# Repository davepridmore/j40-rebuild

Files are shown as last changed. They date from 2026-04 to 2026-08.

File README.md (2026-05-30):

# 1978 Toyota Land Cruiser J40 Rebuild Archive

This repository captures the rebuild of the 1978 Land Cruiser J40 as an evidence-backed archive and project-control workspace:

- WhatsApp chats and media
- manually dropped photos
- tools / parts / labour spend
- legal / admin status tracking
- workstream and phase tracking
- build decisions, milestones, and story outputs

The current setup is intentionally data-first. It gives you a clean place to keep evidence now, while preserving enough structure to produce a restoration story, spend summary, and project control layer as the rebuild moves forward.

## What This Project Tracks

- `tools`: workshop equipment and electrical tools
- `parts`: vehicle parts, consumables, trim, wiring, bodywork materials
- `labour`: painter, electrician, welder, denter, upholstery, mechanical work
- `admin`: registration and other non-restoration vehicle costs, kept separate from restoration totals
- `legal statuses`: ownership transfer, inspection, number-plate position, and document-pack completeness
- `workstreams`: the current phase/state of legal, strip-down, body, electrical, mechanical, interior, and validation work

Only chat content related to this build should be included. The importer treats the `Fj40` group as a build thread and filters the direct `Akbar Khan` export down to restoration-relevant messages only.

## Repository Layout

- `data/config/project.json`: import paths, relevance rules, and project metadata
- `data/config/whatsapp_target_numbers.json`: two-number target map for WhatsApp MCP reads
- `data/manual/expenses.csv`: manually maintained spend ledger with phase/workstream/evidence/payment/delivery/product-link fields
- `data/manual/procurement_queue.csv`: active purchasing queue filtered out of the main expense ledger
- `data/manual/j40_costs_workbook_rows.csv`: normalized extract of `/Users/davidpridmore/Documents/J40_Costs.xlsx` cost-like sheets
- `data/manual/j40_costs_expenses_reconciliation.csv`: workbook-to-ledger match status against `expenses.csv`
- `data/manual/j40_workbook_sheet_profiles.csv`: sheet-by-sheet structure profile across all workbook tabs
- `data/manual/j40_workbook_tidy_backlog.csv`: prioritized workbook tidy issues
- `data/manual/j40_costs_cost_tabs_tidy.csv`: normalized tidy extract of cost tabs (`Tools`, `Parts`, `Substances`, `Wiring`, `Service`)
- `data/manual/reassembly_work_packages.csv`: phased reassembly work packages with gate logic
- `data/manual/reassembly_dependency_edges.csv`: hard and parallel dependencies between reassembly work packages
- `data/manual/component_disposition_plan.csv`: component-level reuse vs refurbish vs repair recommendations
- `data/manual/procurement_decision_matrix.csv`: buy-now vs verify-stock vs defer decisions for open parts rows
- `data/manual/procurement_decision_matrix_pass2.csv`: tub-off-focused second-pass procurement decisions (minimize immediate spend)
- `data/manual/procurement_local_baskets_pass2.csv`: local bundle strategy (rust-minimum, electrical top-up, mechanical Toyota-common bundle)
- `data/manual/brake_system_requirements.csv`: rear brake cable, hard-line, hose, drum, and retaining-clip replacement matrix
- `data/manual/chassis_rubber_requirements.csv`: acquisition/fabrication status matrix for body-mount rubbers, sleeves, cups, shims, and mount hardware
- `data/manual/replacement_pipe_ordering_specs.csv`: curated location/photo/spec matrix for replacement pipes, hoses, hard lines, and the made-to-order coolant pipe sample
- `data/manual/replacement_pipe_photo_intake.csv`: shot-by-shot photo intake checklist for replacement pipe/hose names, placements, media IDs, and measurement targets
- `data/manual/fabrication_handoff_requirements.csv`: UI-facing package list for rubber and electrical fabrication PDF/DXF/SVG handoff
- `data/manual/fabrication/`: ready-to-send DXF/SVG/PDF fabrication packages for rubber recreation and electrical mounting parts
- `data/manual/workbook_tabs/`: per-tab CSV exports for quick review outside Excel
- `data/manual/j40-master-tracker.xlsx`: single Excel workbook generated from `expenses.csv` with `Initial Price`, `Purchase Registration`, `Purchase of Goods`, and `Purchase of Services` tabs
- `data/manual/legal_statuses.csv`: current legal/admin tracker
- `data/manual/workstream_status.csv`: current workstream and phase tracker
- `data/manual/component_jobs.csv`: removable components, outbound jobs, and reassembly-relevant part-flow tracker
- `data/manual/paint_refinish_whatsapp_media_queue.csv`: paint-refinish evidence queue extracted from WhatsApp attachments with send/return/progress buckets
- `data/manual/whatsapp_j40_chat_candidates.csv`: WhatsApp MCP-discovered J40 chat candidates (by profile, score, and fetch status)
- `data/manual/design_decisions.csv`: structured vehicle-design decisions and open design reviews
- `data/manual/photo_inventory.csv`: per-media inventory with component, stage, and confidence tags
- `data/manual/other_build_reference_media.csv`: curated other-build and workshop-sample image manifest for the dashboard
- `data/manual/photo_component_summary.csv`: grouped component summary from the photo inventory
- `data/inbox/photos/`: drop extra project photos here
- `data/raw/imports/`: extracted WhatsApp exports and media
- `data/processed/generated/`: generated message indexes, media indexes, and cost candidates
- `data/pakwheels/<listing_id>/`: listing-gallery snapshots, run history, and archived gallery images
- `data/reference/other_j40_builds/`: drop-zone for images from other J40 builds used as references
- `docs/master-project-plan.md`: the working master plan for the rebuild
- `docs/vehicle-design-spec.md`: the intended end-state of the vehicle itself
- `docs/restoration-story.md`: generated draft story / timeline
- `docs/photo-catalog.md`: generated photo categorization report and lookup guide
- `docs/j40-costs-workbook-reconciliation.md`: workbook registration and reconciliation summary
- `docs/j40-workbook-tabs-and-tidy-plan.md`: workbook-wide tab inventory and tidy plan
- `docs/j40-costs-tidy-extract.md`: normalized cost-tab tidy summary
- `docs/reassembly-dependency-procurement-plan.md`: integrated reassembly sequencing + dependency split + procurement actions
- `docs/procurement-pass2-tub-off.md`: second-pass procurement simplification for tub-off stage and local Pakistan sourcing assumptions
- `docs/suspension-workstream.md`: start-here tracker and installation control sheet for the incoming Ironman Foam Cell suspension set
- `docs/replacement-pipes-workstream.md`: start-here tracker for replacement pipes, hoses, hard lines, and made-to-order pipe samples
- `docs/radiator-workstream.md`: radiator recore/replacement, front retention, hose/cap, and final cooling-system validation workstream
- `docs/ac-hvac-workstream.md`: hidden A/C/HVAC retrofit workstream spanning cabin evaporator, condenser/drier, hose, drain, controls, and wiring
- `docs/gearbox-top-cover-workstream.md`: controlled teardown, inspection, repair/replace, and validation workstream for the gearbox top cover and shift tower
- `docs/gearbox-oil-service-workstream.md`: specific gearbox oil drain, inspection, refill, and buying requirement gate
- `docs/fabrication-handoff-index.md`: send-out index for rubber and electrical fabrication packages
- `photos/index/`: generated lookup folders by component group, specific component, and stage
- `scripts/import_whatsapp.py`: parses chats, extracts media, filters relevance
- `scripts/import_whatsapp_mcp_j40.py`: discovers J40 chats from WhatsApp MCP profiles and exports normalized chat/message/media indexes
- `scripts/generate_story.py`: builds the current restoration story from the indexed evidence
- `scripts/build_master_workbook.py`: builds the single Excel workbook from `expenses.csv`
- `scripts/build_photo_inventory.py`: categorizes `photos/` media and rebuilds inventory + lookup folders
- `scripts/register_cost_workbook.py`: registers and reconciles `J40_Costs.xlsx` against `expenses.csv`
- `scripts/analyze_cost_workbook_tabs.py`: analyzes all workbook tabs, exports per-sheet CSVs, and builds tidy backlog
- `scripts/tidy_cost_workbook.py`: normalizes the five cost tabs into a clean operational extract
- `scripts/build_reassembly_dependency_plan.py`: builds reassembly work packages, dependency graph, component disposition plan, and procurement decision matrix
- `scripts/build_procurement_pass2_tub_off.py`: shrinks the active buy list for tub-off, defers non-baseline scope, and groups local bundle buys
- `scripts/sync_planning_into_cost_workbook.py`: writes all reconciled planning outputs back into `J40_Costs.xlsx` as managed tabs
- `scripts/reconcile_full_cost_workbook.py`: full in-place workbook reconciliation pass (header fixes, mixed-tab splits, tab cleanup, consolidated planning tabs)
- `scripts/build_engine_transmission_comparison.py`: models current-engine vs engine-swap completion costs (including transmission paths) and writes results into `J40_Costs.xlsx`
- `scripts/update_tub_off_refit_and_suspension_plan.py`: writes tub-off to tub-refit control plan, activates the ordered Ironman Foam Cell suspension path, and syncs related workbook tabs
- `scripts/move_wiring_fasteners_to_parts.py`: moves nut/bolt/washer-style rows from `Wiring` into `Parts` so parts tracking stays centralized
- `scripts/track_pakwheels_gallery.py`: snapshots a PakWheels listing gallery and tracks image additions/removals over time
- `scripts/build_project_control_ui.py`: builds `docs/project-control-ui/data.js` for the local project dashboard (workstreams, part ordering, project-step status, WhatsApp samples, and other-build references)
- `scripts/build_paint_refinish_whatsapp_media_queue.py`: extracts paint-refinish photos/videos from WhatsApp media index into send/return/in-progress queues
- `scripts/auth_whatsapp_mcp.sh`: QR-auth helper for WhatsApp MCP profiles (`1` and `2`)
- `tools/generate_rubber_recreation_fabrication_pack.py`: generates the rubber recreation DXF/SVG/PDF fabrication package
- `tools/generate_midi5_plate_mount_rev_c.py`, `tools/generate_midi5_enclosure_rev_d.py`, `tools/generate_relay_mount_rev_c.py`, `tools/generate_relay_mount_rev_d.py`: generate the electrical mounting DXF/SVG/PDF fabrication packages; Rev D is the current MIDI and relay route

## How To Use

1. Drop extra loose photos into `data/inbox/photos/`.
2. Drop reference photos from other J40 builds into `data/reference/other_j40_builds/`.
3. Add curated WhatsApp or workshop sample images to `data/manual/other_build_reference_media.csv`.
4. Update `data/manual/expenses.csv` whenever you buy, quote, receive, install, refund, or defer anything that changes project cost.
   - Put exact online item URLs in `product_link`; multiple URLs can be separated with ` | ` for bundle rows.
5. Set `procurement_stage` in `data/manual/expenses.csv` so each line item stays operationally visible:
   - `purchase_ready`: ready to order now
   - `ordered_pending_delivery`: order has been placed and is waiting to arrive
   - `needs_confirmation`: user says it may already be ordered or delivered, but proof still needs to be reconciled
   - `received_candidate`: likely purchased / delivered, but still needs item-level confirmation
   - `next_phase_purchase`: valid item, but not yet on the critical path
   - `researching`: still being compared or scoped
   - `deferred_until_body_closed`: do not buy until body/floor work reaches the right point
   - `deferred_optional`: non-baseline upgrades or nice-to-haves
   - `received` / `completed`: no longer belongs in the active queue
6. Use `data/manual/procurement_queue.csv` as the working buy list and reconciliation list.
7. Update `data/manual/legal_statuses.csv` whenever a legal/admin step changes state.
8. Update `data/manual/workstream_status.csv` whenever a phase actually moves or gets blocked.
9. Update `data/manual/component_jobs.csv` whenever a removable component is tagged, sent out, returned, stored, or reinstalled.
10. Rebuild the local photo catalog and lookup folders whenever you add files into `photos/`:

```bash
python3 scripts/build_photo_inventory.py
```

To pull selected recent media from Google Photos via Picker API into `photos/`:

```bash
python3 scripts/import_google_photos_picker.py \
  --client-secrets /Users/davidpridmore/.codex/client_secret.json \
  --recent-days 120 \
  --open-browser
```

Personal-account on-demand command (personal OAuth client, import + filter + analysis refresh):

```bash
./scripts/run_personal_photos_picker_on_demand.sh
```

Optional environment overrides:

```bash
CLIENT_SECRETS=/absolute/path/to/oauth_client.json \
RECENT_DAYS=30 \
MOVE_NON_CAR=1 \
./scripts/run_personal_photos_picker_on_demand.sh
```

After import, run:

```bash
python3 scripts/build_photo_inventory.py
python3 scripts/reconcile_component_jobs_photo_inventory.py
python3 scripts/build_paint_refinish_media_queue.py
python3 scripts/build_paint_refinish_whatsapp_media_queue.py
```

`build_paint_refinish_media_queue.py` writes `data/manual/paint_refinish_media_queue.csv` with three evidence buckets:
`prepared_for_send_out`, `returned_from_painter`, and `in_progress_video`.

`build_paint_refinish_whatsapp_media_queue.py` writes `data/manual/paint_refinish_whatsapp_media_queue.csv`
from `data/processed/generated/media_index.csv` and `whatsapp_messages.json` with the same three buckets plus
`classification_confidence` and `classification_reason` for review.

To avoid custom client-secrets entirely, you can use `gcloud` ADC credentials:

```bash
gcloud auth application-default login \
  --scopes=https://www.googleapis.com/auth/photospicker.mediaitems.readonly

python3 scripts/import_google_photos_picker.py \
  --auth-mode adc \
  --recent-days 120
```

Automated ingest mode (recommended in this repo):

- Drop Google Takeout archives into: `data/inbox/takeout/`
- Supported archive formats: `.zip`, `.tgz`, `.tar.gz`
- Cron scanner script: `scripts/scan_takeout_ingest_once.sh`
- Install cron automation: `scripts/install_photo_ingest_cron.sh`
- Remove cron automation: `scripts/uninstall_photo_ingest_cron.sh`
- Current automation status file: `docs/photo_ingest_automation_status.md`

Helper to stage archives from Downloads:

```bash
./scripts/stage_takeout_from_downloads.sh
```

On-demand full ingest + car-related filtering + analysis refresh:

```bash
./scripts/run_photo_ingest_on_demand.sh
```

This command stages archives, ingests media, moves probable non-car files to `photos/non_car_review/`, and refreshes inventory/catalog/reconciliation outputs.

`rclone` note:

- Google Photos Library API policy now limits API reads to media created by the same app/client.
- This means `rclone` is no longer reliable for full phone-library sync in this project.
- Use the Picker on-demand flow above for recent selected media, or Google Takeout ingest for full-library snapshots.

If you still want to run `rclone` (for app-created media only), use:

```bash
./scripts/sync_google_photos_pipeline.sh pridmoredave-gphotos:
```

This command:

- copies recent media from `media/all` into `photos/` (`MAX_AGE` default `540d`)
- rebuilds `data/manual/photo_inventory.csv`
- refreshes `docs/photo-catalog.md`
- refreshes `data/manual/component_jobs_photo_reconciliation.csv` and its report

You can tune the pull window, for example:

```bash
MAX_AGE=180d ./scripts/sync_google_photos_pipeline.sh pridmoredave-gphotos:
```

9. Register and reconcile the external workbook whenever it changes:

```bash
python3 scripts/register_cost_workbook.py --workbook /Users/davidpridmore/Documents/J40_Costs.xlsx
```

10. Run workbook-wide tab analysis and tidy extraction:

```bash
python3 scripts/analyze_cost_workbook_tabs.py --workbook /Users/davidpridmore/Documents/J40_Costs.xlsx
python3 scripts/tidy_cost_workbook.py --workbook /Users/davidpridmore/Documents/J40_Costs.xlsx
```

11. Build reassembly and procurement execution planning artifacts:

```bash
python3 scripts/build_reassembly_dependency_plan.py
```

12. Run the tub-off second-pass procurement simplification:

```bash
python3 scripts/build_procurement_pass2_tub_off.py
```

13. Sync all planning/reconciliation outputs into the main workbook (keeps original tabs and adds managed planning tabs):

```bash
python3 scripts/sync_planning_into_cost_workbook.py --workbook /Users/davidpridmore/Documents/J40_Costs.xlsx
```

The sync command creates a timestamped backup copy before writing:

- `/Users/davidpridmore/Documents/J40_Costs.backup_YYYYMMDD_HHMMSS.xlsx`

14. Run a full workbook reconciliation and simplification pass when tabs drift or mixed content appears:

```bash
python3 scripts/reconcile_full_cost_workbook.py --workbook /Users/davidpridmore/Documents/J40_Costs.xlsx
```

15. Build the engine/transmission scenario comparison and write it into the workbook:

```bash
python3 scripts/build_engine_transmission_comparison.py --workbook /Users/davidpridmore/Documents/J40_Costs.xlsx
```

16. Sync tub-off/refit execution control, mount/rubber procurement, and ordered Ironman Foam Cell suspension decisions:

```bash
python3 scripts/update_tub_off_refit_and_suspension_plan.py --workbook /Users/davidpridmore/Documents/J40_Costs.xlsx
```

17. Move fastener rows from `Wiring` into `Parts`:

```bash
python3 scripts/move_wiring_fasteners_to_parts.py --workbook /Users/davidpridmore/Documents/J40_Costs.xlsx
```

This command creates a backup before edits:

- `/Users/davidpridmore/Documents/J40_Costs.full_reconcile_backup_YYYYMMDD_HHMMSS.xlsx`

18. Rebuild dashboard data for the local project-control UI:

```bash
python3 scripts/build_project_control_ui.py
```

Then start the local dashboard server:

```bash
./start-dashboard.command
```

15. Run:

```bash
python3 scripts/import_whatsapp.py
python3 scripts/import_whatsapp_mcp_j40.py
python3 scripts/build_paint_refinish_whatsapp_media_queue.py
python3 scripts/generate_story.py
python3 scripts/build_master_workbook.py
```

The first command extracts and indexes chats, media, and cost candidates.
The second command discovers J40-related chats from your two WhatsApp MCP profiles and exports normalized chat/message/media tables.
The third command builds the WhatsApp-derived paint evidence queue.
The fourth command produces the draft story and spend snapshot.
The fifth command produces the single Excel workbook for review and sharing, focused on initial pricing and purchase registration control.

The workbook tabs are centered on purchase control:

- `Initial Price`: quoted/initial prices captured so far
- `Purchase Registration`: registration state for each row (`registered`, `registered_needs_confirmation`, `quote_only`, `planned`, `researching`)
- `Purchase of Goods`: goods-only rows (`tools` + `parts`)
- `Purchase of Services`: services-only rows (`labour` + `admin`)

To keep a PakWheels listing gallery tracked over time, run:

```bash
python3 scripts/track_pakwheels_gallery.py --url "https://www.pakwheels.com/used-cars/toyota-land-cruiser-1984-for-sale-in-islamabad-10076971"
```

Each run appends a timestamped snapshot and updates:

- `data/pakwheels/<listing_id>/gallery_runs.csv`
- `data/pakwheels/<listing_id>/gallery_history.csv`
- `data/pakwheels/<listing_id>/archive/` (deduplicated image files)
- `data/pakwheels/<listing_id>/snapshots/<run>/` (per-run URLs + manifest)

## Cost Control Notes

- `phase` and `workstream` tie spend to the plan in `docs/master-project-plan.md`.
- `evidence_ref` should point to a WhatsApp message id, invoice, receipt filename, or similar proof anchor.
- `payment_status` and `delivery_status` should be maintained independently.
- `procurement_stage` is the operational layer on top of financial status; use it to separate "ready to buy now" from "quoted", "received but not fully reconciled", and "deferred".
- Keep `admin` costs separate from restoration costs.
- Quotes and optional upgrades should stay visible, but they should not be confused with confirmed baseline spend.
- `data/manual/procurement_queue.csv` should only contain live items that still need purchase, confirmation, or decision work.

## Seeded Data

The repo already includes:

- the two WhatsApp exports you pointed to in `/Users/davidpridmore/Downloads`
- your current purchase list, separated into received / planned / research items
- known spend items and quote items visible in the chats

Amounts without a confirmed number stay in the ledger with `amount_status=missing` so they are visible but do not distort totals.

## Gmail / Order Status

Project-local MCP is configured in `.ai/mcp/mcp.json` with server `google-orders-receipts` (Gmail + Drive only).

One-time setup:

```bash
bash scripts/auth_orders_receipts_mcp.sh
```

If your OAuth credentials are in a different file, set:

```bash
GOOGLE_WORKSPACE_CREDENTIALS_PATH=/absolute/path/to/credentials.json bash scripts/auth_orders_receipts_mcp.sh
```

Build a full order/receipt verification queue for all `parts` and `tools` rows:

```bash
python3 scripts/build_orders_receipts_audit_queue.py
```

This writes `data/manual/orders_receipts_audit_queue.csv` with:

- audit priority (`high|medium|low`)
- recommended audit status per row
- Gmail/Drive search queries for order confirmation and receipt/invoice proof

Import recent project-relevant Gmail messages:

```bash
python3 scripts/import_google_emails_mcp.py --date-tag 2026-05-18
```

The importer uses the same `j40-orders-receipts` MCP profile, searches recent project/order messages plus exact order references from `data/manual/orders_receipts_audit_queue.csv`, and writes dated `comms_ingest_*` CSV/JSON artifacts under `data/processed/generated/`.

## WhatsApp MCP (2 Numbers)

Project-local MCP is configured in `.ai/mcp/mcp.json` with:

- `whatsapp-number-1`
- `whatsapp-number-2`

Each server uses a separate auth/session directory and media storage path:

- `.ai/mcp/auth/whatsapp-number-1` -> `data/raw/imports/mcp_whatsapp_number_1`
- `.ai/mcp/auth/whatsapp-number-2` -> `data/raw/imports/mcp_whatsapp_number_2`

One-time QR auth for each number profile:

```bash
bash scripts/auth_whatsapp_mcp.sh 1
bash scripts/auth_whatsapp_mcp.sh 2
```

After each login is confirmed, stop the auth process with `Ctrl+C`.

Set your two target numbers in:

- `data/config/whatsapp_target_numbers.json`

Use E.164 format (example: `+923001234567`), one number for each server profile.

Import J40-focused chat metadata and media indexes from the two WhatsApp MCP profiles:

```bash
python3 scripts/import_whatsapp_mcp_j40.py
```

This writes:

- `data/manual/whatsapp_j40_chat_candidates.csv`
- `data/processed/generated/mcp_whatsapp_j40_messages.json`
- `data/processed/generated/mcp_whatsapp_j40_media_index.csv`

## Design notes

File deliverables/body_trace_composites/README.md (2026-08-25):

# J40 Cabin and Floor Concept Release — 2026-08-25

Saved outputs:

- `j40_front_floor_measured_doghouse_trace_20260825_v2.png` — front-floor plan with the high forward enclosure, fast-tapering shoulders, and compact squared seat-side tail.
- `j40_front_doghouse_measured_side_profile_20260825_v1.png` — longitudinal height/profile study.
- `j40_rear_tub_measured_side_bench_layout_20260825_v1.png` — rear-tub side-bench layout preserving the centre aisle.
- `j40_front_cabin_photoreal_transmission_view_20260825_v1.png` — reference-derived appearance study viewed from immediately behind the front-seat line toward the transmission and dashboard.

The labels on the measured sheets are approximate photographic reads and concept geometry. They are not cut-ready drawings. Confirm every dimension square on the stripped body with the drivetrain, shifters, seats, mounts, pedal travel, service access, and drivetrain movement in their final positions.

## Photoreal generation prompt

> Create a reference-derived photorealistic landscape visualization inside the same classic Toyota Land Cruiser J40 cabin. Camera position is just behind the front-seat line, centered and about seated eye height, looking forward toward the transmission tunnel, engine doghouse, pedals, firewall, and the cream dashboard. Show the rebuilt finished interior after the entire floor has been replaced: clean accurately fabricated ribbed steel floor panels and a removable squared sheet-metal transmission/engine cover. The cover must be high and broad at the firewall/dash to clear the real drivetrain shown in the reference photo, then follow its mechanical contour downward and taper aggressively. The part closest to the seats must become extremely narrow, low, and short, terminating before the seat cushions and leaving generous foot/seat clearance on both sides. Use crisp folded facets, small realistic bend radii, a neat perimeter flange with evenly spaced removable fasteners, subtle seams, and two correctly positioned gear/transfer levers through tidy black rubber boots on the high forward portion. Finish the new floor and cover in durable satin warm ivory matching the dashboard, with believable minor texture and soft reflections. Keep authentic J40 dashboard, door openings, inner sill, pedals, proportions, and workshop context from the reference. Include only the lower inner corners of the two front seat cushions at the far left and right foreground so the narrow short rear tail and clearance are obvious. No people, no labels, no dimension text, no cutaway, no exposed gearbox, no loose tools or clutter. Natural workshop daylight, realistic materials, lens perspective, high detail, documentary automotive restoration photography, 16:9 composition.

Generation references:

- the supplied stripped-cabin/drivetrain photograph
- `j40_front_floor_measured_doghouse_trace_20260825_v2.png`
- `j40_front_doghouse_measured_side_profile_20260825_v1.png`
- `reference_front_drivetrain_profile_20260825.png`

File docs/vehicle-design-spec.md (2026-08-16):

# Vehicle Design Spec

## Purpose

This document defines the intended end-state of the J40 as a vehicle, not just as a project. It turns the current chat history and project evidence into a coherent design target that can guide parts, labour, sequencing, and trade-offs.

## Design Position

- Vehicle: 1978 Toyota Land Cruiser J40
- Current controlled basis: ex-military J40 converted to diesel, with the fitted engine positively identified from the owner-supplied block-stamp photograph as Toyota `2H`, serial `117299` (`2H-117299`): 3,980 cc, inline-six, 12-valve OHV, naturally aspirated diesel. Classify the fitted gearbox as Toyota `H55F` five-speed with high confidence: the existing whole-assembly photographs show the Toyota H41/H55F-family case and transfer-adaptor layout, while owner confirmation and the earlier WhatsApp/video record establish five forward gears. A unique gearbox assembly serial has not been captured; visible `33111`, `BYD`, and separate `3` marks are casting/part marks, not a serial. The August 2 steering photographs identify the as-fitted unit by housing, valve-head, port, sector-shaft, pitman-arm and pedestal-mount geometry as a Toyoda Koki late-40-Series factory-type hydraulic steering gear with high confidence. It is not original as-built equipment for this 1978 chassis, but is consistent with a later J40-family retrofit; the raised `25050` is a casting identifier, not a serial or complete Toyota service number. Exact `44110-xxxxx` identity remains unconfirmed.
- Design mode: OE-adjacent restoration with selective usability upgrades
- Intended use: reliable road-going classic 4x4 with improved drivability, lower cabin noise, cleaner wiring, and a more coherent interior
- Design rule: preserve the character of the truck while removing obvious hacks, noise, water ingress, and avoidable drivability pain

Evidence basis:

- `mcp_whatsapp_j40_messages.csv:1780` / `2026-05-17T11:05:54Z`, TLC 40 Series Owners: owner note says "1978 ex military, converted to diesel".
- `mcp_whatsapp_j40_messages.csv:1781` / `2026-05-17T11:06:16Z`, TLC 40 Series Owners: group member says it belonged to Jahanzaib from Lahore.
- `mcp_whatsapp_j40_messages.csv:1797` / `2026-05-17T11:47:47Z`, TLC 40 Series Owners: group member says "Your J40 has 2h engine with 5 speed gear. It was sold by Jahanzeb".
- `mcp_whatsapp_j40_messages.csv:1802` / `2026-05-17T12:10:28Z`, TLC 40 Series Owners: group member says Jahanzeb left the group after selling it.
- Owner-supplied block-stamp photograph received 2026-08-02 shows the `2H` engine code followed by serial `117299`. Record the engine as `2H-117299`. The supplied description places it in early-to-mid-1980s production, but no factory serial-to-date record is held in the project, so the build year remains an estimate rather than a procurement datum.

## Design North Star

- Exterior and body should read as a proper J40, not a heavily modernized custom build.
- Mechanical and electrical systems should feel tighter, safer, and more dependable than the current truck.
- Interior should become cleaner, quieter, and more usable without losing the basic utilitarian identity of the vehicle.
- Upgrades should mostly be hidden, reversible, or visually restrained unless there is a clear reason not to do so.

## Design Principles

- `OE-adjacent, not concours`: aim for something that could plausibly have been built well, rather than a museum-original truck.
- `Function over gimmicks`: every visible change should improve use, durability, serviceability, or weather protection.
- `Repair before upgrade`: structural, weather, wiring, and baseline mechanical integrity come before comfort and audio.
- `Document every deviation`: if the build leaves stock, the reason and resulting spec should be recorded.
- `Serviceable by the next person`: wiring, parts choices, and fastener decisions should not trap the next owner or mechanic.

## Evidence-Based Direction

The following signals appear directly in chat evidence and form the backbone of the design:

- steering currently feels poor and a power-steering upgrade is desired
- electrical system should be stripped and rebuilt cleanly
- random LEDs, speakers, light bars, and extra wiring have already started coming out
- cabin noise reduction matters
- roof drainage/body issues matter
- removable body parts are expected to be sent out individually for quality repair
- bench-seat conversion is being considered
- interior should be refreshed after rust, sealing, and floor treatment
- a flush-mounted Android screen and some audio upgrades are being explored
- premium shocks and brake/steering upgrades are on the table, but a full suspension conversion is not baseline work

## Vehicle-Level Target

### 1. Exterior and Body

Target:
- straight, properly repaired body panels
- repaired roof channels and resolved water ingress paths
- corrected rust and pinhole issues before finish materials go down
- period-appropriate outward appearance
- no visibly half-finished panel, seal, or trim decisions

Design interpretation:
- keep the truck visually recognisable as a J40
- favor good panel fit and corrosion protection over radical visual customization
- removable components should be restored to a consistent standard, not patched at mixed quality levels

### 2. Chassis and Underbody

Target:
- structurally sound chassis
- repaired and protected floor
- rust treatment and sealing done in the correct order
- underbody decisions driven by longevity, not shortcuts

Design interpretation:
- structural work is a mandatory design layer, not hidden workshop housekeeping
- floor repairs, primer, seam treatment, and bed/floor coatings should form a coherent system

### 3. Mechanical Character

Target:
- retain the current engine for now unless hard inspection evidence pushes against that
- service and baseline the powertrain before entertaining replacement ideas
- reduce “old truck plus deferred maintenance” feel without turning the build into an engine-swap project

Design interpretation:
- current bias is toward keeping the existing engine
- mechanical baseline should deliver confidence, not necessarily originality purity
- replacement-engine thinking remains exploratory and off the current baseline path
- use Toyota 2H workshop data and the measured as-fitted interfaces for engine-specific service parts, brackets, hoses and turbo hardware; the serial confirms the engine family but does not by itself prove every accessory or conversion interface

### 4. Steering, Brakes, and Ride

Target:
- steering should no longer feel vague or ship-like
- braking should feel modern enough to trust
- ride should be more controlled without becoming overbuilt or financially absurd

Proposed design hierarchy:
1. steering rebuild and wear-item correction
2. ordered Ironman Foamcell kit content check and suspension installation
3. brake baseline
4. replace the fitted late-40-Series factory-type hydraulic gear with a component-in-hand RHD J60/HJ60 steering-box upgrade, matched pitman/linkage and collapsible shaft; retain the current unit as the as-fitted baseline and match the 2H pump drive, reservoir and hoses to the selected J60 box
5. final ride-height, caster, and alignment validation

Design interpretation:
- power steering is already present as a later J40-family factory-type retrofit, but the planned upgrade remains a RHD J60/HJ60 hydraulic box conversion. The current box identification establishes the baseline; it does not cancel the J60 plan. The J80 route is superseded
- the Ironman Foamcell kit is now the suspension baseline
- front disc brakes fit the “usable classic” direction
- full spring / 4-link conversion is explicitly outside the baseline design

### 5. Electrical Architecture

Target:
- one coherent documented wiring system
- labeled circuits
- sensible fuse and relay layout
- proper cable protection, routing, grounds, and connectors
- removal of random accessory-era wiring clutter

Design interpretation:
- baseline circuits first: starting, charging, lights, horn, wipers, gauges, heater, reverse lights
- add-ons should hang off a clean architecture rather than distort it
- hidden reliability matters more than chasing a superficially stock loom
- serviceability and documentation matter more than purity

### 6. Lighting

Target:
- simpler, cleaner lighting with better reliability
- remove poor-quality add-on lighting clutter
- improve headlight performance via proper relays and better-supported hardware

Design interpretation:
- H4-style headlight upgrade is aligned with the evidence-based electrical plan
- light bars and random accessory lighting should not define the truck

### 7. Interior

Target:
- quieter cabin
- cleaner, less hacked interior
- refreshed trim after leaks, rust, and floor layers are solved
- more coherent seating and cargo usability

Design interpretation:
- sound deadening, foam, and carpet are part of the intended final package
- bench-seat conversion is a viable interior direction if mounting and usability work cleanly
- interior should feel restored and usable, not luxury-custom

### 8. Dashboard and Infotainment

Target:
- if modern infotainment is retained, it should be integrated cleanly rather than looking bolted on
- fuse-box and service access should not be sacrificed for speakers or screen placement

Design interpretation:
- the active Rev I V44 appearance direction is one visibly closed, balanced centre panel between the unchanged OEM glovebox and speedometer. Its two upper corners use smooth radii consistent with the retained glovebox and speedometer openings; its side seams close the panel at those OEM boundaries; and its bottom is exactly the unchanged factory lower dashboard edge with 0 mm drop. It replaces the original ashtray pressing, central rectangular opening and lower slot without continuing to the far-right dashboard end. Every perimeter edge and radius must be traced directly before production release; V43's sharp-corner study and V41/V42 are superseded boundary studies
- the replacement section carries the purchased Pioneer DMH-AP6650BT with its 229 × 131 × 13 mm manufacturer-published front/nose flush with the panel. The V46-D1 A1 1:1 component sheet fixes this reference envelope, the 188 × 108 × 37 mm chassis, 196.608 × 114.15 mm effective display area and the official Schneider selector envelopes without pretending to fix their installation coordinates. All panel-perimeter, speedometer-side termination, corner-radius, aperture, rear-mount, duct and position data remain HOLD pending M1–M9 physical traces, actual parts and a complete rear buck; the controlled links are indexed by `data/manual/fabrication/dashboard_lcd_hvac_fascia_rev_i/README.md`
- the vehicle is right-hand drive. One line below the LCD carries seven bought black long-lever selectors—WIPERS, LIGHTS, SPOTS, AUX, BLOWER, A/C and FUEL STOP—plus a separate red HAZARD. Wipers, Lights and Blower are 3-position; Spots, Aux, A/C and Fuel Stop are 2-position. The Fuel Stop selector is a low-current RUN/STOP request subject to EEI-003; key OFF remains authoritative and the original manual stop cable remains the emergency fallback
- any screen/audio plan must follow the cleaned electrical architecture and final dash packaging
- visible aftermarket clutter is contrary to the design direction

### 9. Audio

Target:
- restrained audio upgrade if kept
- no wiring mess, no compromised service access, no visible nonsense

Design interpretation:
- speaker wire, amplifier kit, and under-seat subwoofer are optional candidates
- audio should stay subordinate to the vehicle architecture
- if audio packaging conflicts with wiring access or OE-adjacent dash layout, audio loses

## Proposed Final Character

The target truck is:

- visually classic
- mechanically more confidence-inspiring
- electrically modern in reliability but not loud in appearance
- quieter and more weatherproof inside
- upgraded where the truck is genuinely weak
- restrained where novelty would compromise the identity of the build

In practical terms, that means:

- clean body and roof repair
- repaired floor and proper sealing stack
- re-architected wiring
- improved headlights and basic electrical usability
- steering/brake/suspension improvements that make it nicer to drive
- OE-adjacent interior with noise control and cleaner trim
- optional modern screen/audio only if integrated cleanly

## Proposed System Decisions

| System | Proposed Direction | Decision State |
| --- | --- | --- |
| Body style | Keep recognisable J40 form and panel language | `proposed` |
| Body restoration | Repair removable panels individually to a consistent standard | `proposed` |
| Roof | Remove, correct channels/water issues, refinish properly | `proposed` |
| Chassis/floor | Repair and protect before finish layers | `proposed` |
| Engine | Retain and baseline Toyota `2H-117299`, 3,980 cc naturally aspirated inline-six diesel; use the stamp photo as identity evidence and measure all conversion interfaces | `identified_health_gate` |
| Turbo | Pursue the 2H low-mount CT26-flange / CT26-pattern TD05H 16G direction only after engine-health, goods-receipt and vehicle-clearance gates; commission at `5-7 psi` | `conditional_package_direction` |
| Steering | Baseline is the fitted Toyoda Koki late-40-Series factory-type hydraulic gear, exact service number open. Planned upgrade is a component-first RHD J60/HJ60 box, matched pitman/linkage and collapsible shaft with a measured, pressure/flow-matched 2H pump circuit; J80 is superseded | `j60_upgrade_component_gate` |
| Brakes | Upgrade toward more confidence-inspiring road use | `proposed` |
| Suspension | Ironman Foamcell kit ordered; track two shipments and validate fitment | `ordered` |
| Full suspension conversion | Out of baseline scope | `deferred` |
| Wiring | Full clean rewire / respin with documented architecture | `proposed` |
| Lighting | Relay-based clean lighting, better headlight performance | `proposed` |
| Interior finish | Sound deadening + foam + carpet after body sealing | `proposed` |
| Seating | Bench-seat conversion under packaging review | `under_review` |
| Dash | Keep visually disciplined, avoid clutter | `proposed` |
| Android screen | Optional, only if flush and integrated cleanly | `under_review` |
| Audio system | Optional and subordinate to serviceability | `under_review` |

## Baseline vs Optional

### Baseline Design Scope

- body and rust correction
- roof/water-path repair
- floor repair and sealing stack
- coherent wiring reset
- basic lighting correctness
- steering/brake baseline improvement
- weatherproofing and interior noise reduction
- trim reassembly to a coherent standard

### Optional Design Scope

- flush Android head unit
- amplifier and subwoofer
- premium non-essential audio packaging
- ambitious suspension experimentation
- engine replacement

## Open Design Questions

- What visual finish direction is intended for the exterior: preserve current palette, return to stock-adjacent color, or choose a new classic-appropriate finish?
- Are bench seats actually wanted after packaging/ergonomics review, or just being considered?
- Which exact RHD J60/HJ60 box, pitman arm, shaft/couplers and measured drag-link solution will be acquired, and how do they overlay the identified fitted J40-type gear and chassis interfaces?
- Does the truck want a discreet hidden modern screen, or would a more period dashboard treatment be better?
- What is the acceptable line between OE-adjacent and modernized in visible cabin elements?

## Immediate Design Tasks

1. Freeze the build as `OE-adjacent + hidden usability upgrades` unless a different brief is chosen.
2. Decide whether the Android/audio path is truly desired or should be cut from the first-pass design.
3. Decide whether the interior target is bench-seat based or current-seat based.
4. Create a paint and finish brief once more body evidence is available.
5. Create a wiring architecture sheet once the strip-down exposes the actual live circuits.
6. Complete the fitted J40-type hydraulic-gear interface survey, then acquire and bench-inspect the complete matched RHD J60/HJ60 conversion set before releasing any chassis, linkage or hose fabrication.

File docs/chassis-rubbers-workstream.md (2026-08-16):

# Chassis Rubbers Workstream

Date: 2026-05-08

Purpose: keep the chassis/body rubber order aligned with the current evidence. The current Longman order is custom rubber, with bump-stop rubber now controlled by the May 31 exact front-stop photos. Rear/back stops use the same front-stop shape and fixture pattern, made longer to the `70 mm` family height. Body-mount steel washers, cup/seat washers, crush sleeves, shims, bolts, and captive-thread repairs are inspected or ordered separately because they control the stack but are not custom rubber pieces.

The Chassis Rubbers dashboard section now also carries the complete J40 rubber coverage matrix from [rubber_ordering_specs.csv](../data/manual/rubber_ordering_specs.csv). Treat the Longman pack as the body/chassis custom-rubber subset, and treat the all-rubbers matrix as the guardrail that keeps hoses, grommets, bushes, mounts, weatherstrips, HVAC rubber, seals, plugs, and hangers in their own buy gates.

Current supplier pack:

- [Longman rubber order spec](longman-rubber-order-spec-20260508.md)
- [Longman rubber order CSV](../data/manual/longman_rubber_order_specs.csv)
- [Current order preview](../data/manual/fabrication/rubber_recreation_rev_a/chassis_rubber_current_order_preview_rev_a.svg)
- [Chassis rubber location map](../data/manual/fabrication/rubber_recreation_rev_a/chassis_rubber_location_map_rev_a.svg)
- [Complete chassis rubber SVG preview](../data/manual/fabrication/rubber_recreation_rev_a/chassis_rubber_all_drawings_preview_rev_a.svg)
- [Parametric 3D rubber models](../data/manual/fabrication/rubber_recreation_rev_a/models_3d/README.md)
- [Bump-stop fabrication spec](bump-stop-fabrication-spec-20260504.md)
- [All-rubbers ordering matrix](../data/manual/rubber_ordering_specs.csv)

## Complete J40 Rubber Coverage

Use the all-rubbers matrix before any rubber purchase, even when the immediate work is the body/chassis mount stack. It prevents a body-mount supplier quote from absorbing unrelated items that should be inspected, sample-matched, receipt-checked, or deferred.

| Coverage group | Rows | Current position |
| --- | --- | --- |
| Body/chassis mount and hardware | `RUB-001` to `RUB-002` | Current Chassis Rubbers workstream. `RUB-001` is the Longman custom-rubber pack; `RUB-002` is separate sleeves/cups/shims/hardware. |
| Grommets and pass-through seals | `RUB-003` to `RUB-004`, `RUB-017` | Buy/top-up only by measured firewall/body holes and current inventory; floor/body plugs defer until repair and coating are stable. |
| Powertrain, steering, suspension, and intake rubber | `RUB-005` to `RUB-008`, `RUB-026` to `RUB-027` | Engine mounts are no-active-purchase; gearbox mounts, steering bushes, bump stops, and intake ducting are inspect/sample-match gates; Ironman bushes are receipt-check first. |
| Brake, clutch, fuel, coolant, vacuum, and formed-pipe rubber | `RUB-009` to `RUB-016`, `RUB-028` | Safety/fluids stay in rated-hose gates. Brake hoses must be complete crimped assemblies, fuel hose must be fuel-rated, and coolant/heater hose must be EPDM coolant/heater hose. |
| Exhaust, pedal, HVAC, and duct rubber | `RUB-022` to `RUB-025` | Exhaust hanger/cushion rubber waits for final support geometry; pedal rubber is later; HVAC barrier hose, drain, O-rings, duct, and defrost hose are current HVAC refit items. |
| Body, window, roof, bonnet, and rear-door weatherstrip | `RUB-018` to `RUB-021`, `RUB-029` to `RUB-032` | Deferred until body/window/hardtop/rear-closure fit is known; do not roll these into the Longman chassis mount quote. |

Current count: `32` all-rubber rows across `16` workstream categories. `9` rows are buy/lock-now or receipt-check work, `10` are current-build required, and the remaining rows are inspect-first, conditional, no-active-purchase, or deferred.

## Current Order Basis

The old release specs assumed cup/seat washers and a controlled crush sleeve. That remains true for stack control, but the tub/chassis photos do not prove a shaped rubber socket. Treat the main body mounts as function-first isolator pads.

The measured old-rubber photos are no longer being treated as an unknown-dimension problem. They are the quote and first-article basis for the current Longman rubber pieces. The remaining open work is station mapping and dry-fit release:

- Which measured part belongs at which vehicle station.
- Whether the square pad footprint clears the actual landing face at that station.
- Whether the sleeve/cup/shim/bolt stack clamps through the sleeve without over-crushing the rubber.
- Whether any first article needs local corner/end trimming after it is placed on the vehicle.

Critical controls:

- Installed rubber height and final compression.
- Central `18.0 mm` bore for Toyota `90560-12009` style sleeve.
- Bolt clamps through the steel sleeve, not by crushing rubber until metal contact.
- Bearing area covers the landing faces without running onto bends, seams, weld lips, repairs, or rust-thinned edges.
- Similar hardness across the set, target Shore A `60 +/-5`.
- Solid new automotive rubber only: no tyre rubber, crumb rubber, sponge, foam, mixed offcuts, salvage rubber, or unmarked old stock.

Preferred custom shape for the main pads is square. Release trimming only if a later station photo proves a specific corner or edge needs relief.

## Location And Coverage Check

The current Toyota GR Heritage 40-series list checked on 2026-05-28 does not expose a complete body/chassis rubber kit for this scope. EPC-style Toyota listings and aftermarket suppliers do confirm the usual body-mount cushion/spacer/shim families and early/late 40-series kit splits. That confirms the required families exist, but it does not replace this vehicle's station map, dry-stack checks, or the current Longman square-pad route. The source links are recorded in [Longman rubber order spec](longman-rubber-order-spec-20260508.md).

Use `../data/manual/fabrication/rubber_recreation_rev_a/chassis_rubber_location_map_rev_a.svg` as the dashboard/install location guide:

- Single `80 x 80 x 24` body pad: main tub-to-chassis mount stack, ordered as a generous flat-square batch so any station that proves low can use two stacked pads.
- `FS-OVAL`: separate left/right front support / nose-extension isolators.
- `FS-STRIP-L/R`: left/right underfloor front-support/body-support strip landings.
- `BUMP-60010-LONG`: rear/back long-family axle-to-chassis bump-stop stations, plus any Toyota-controlled front-left long station if confirmed on this vehicle.
- `BUMP-60020-SHORT`: exact front/right-front axle-to-chassis bump-stop station.
- `BODY-LINER-FULL-WIDTH-HOLD` and `EXH-HGR-90917`: hold/reference controls only, excluded from the purchase 3D view.

Main body rubbers stay deliberately simple: the active route is one plain `80 x 80 x 24` square body-pad size. The smaller `22 mm` body-rubber line is removed from the order. The Longman quote now carries `30` flat square pads so there is enough stock for stations that prove they need two stacked pads, not a release for new ribbed or shaped body-rubber variants.

## Three Things To Order

The Longman request should be presented as three supplier-facing order groups, with the part IDs below retained as drawing and first-article controls:

| Order group | What to order | Qty |
| --- | --- | --- |
| 1. Simple `80 x 80` body pads | Single `80 x 80 x 24` body-pad size; smaller `22 mm` pad line removed | `30` body pads |
| 2. Front support / body-support rubbers | `FS-OVAL` plus `38 x 8` strip stock for the left/right underfloor strips | `2` oval pads, `2 m` of strip stock; cut `2 x 420 mm` strips after dry-fit |
| 3. Bump stops | Long rear/back bump stops plus short exact front/right-front stop | `3` long stops and `1` short stop |

## Rubber Order Lines

| ID | Status | Qty | Current spec | Release gate |
| --- | --- | ---: | --- | --- |
| `BM-ISO-LG` | Released for quote / first article as the single active body-pad size | `12 base + 18 stacking/trim spares` | 3D envelope `80 L x 80 W x 24 H mm`; square flat pad; flat parallel faces; plan corners `R1.5`; top/bottom edge break or chamfer `1.0 mm` max; `18.0 mm` through bore; smaller `22 mm` line removed from order; use a second identical pad only where dry-fit proves extra height is needed. | Station mapping, footprint check, sleeve/cup/shim dry-stack, any two-pad station proof, and compression check before final install. |
| `FS-OVAL` | Released for quote / first article | `2` | 3D envelope `96 L x 64 W x 15 T mm`; capsule ends `R32`; outer edge break `0.5-1.0 mm`; two `12 mm` holes at `64 mm` centres; rectangular relief only if old sample confirms it is functional. | Caliper-confirm hole centres, thickness, insert/boss/relief construction before final pair. |
| `FS-STRIP-L` | Released for quote / first article | `1 cut from stock` | Cut `420 L x 38 W x 8 T mm` from a shared `2 m` order of `38 x 8 mm` plain strip stock after dry-fit; plan corners `R1.5`; top/bottom edge break `0.5-1.0 mm`; no through-holes in the rubber by default; Shore A `60 +/-5`. | Dry-fit on the actual landing, allow for a non-perfectly-straight run, then apply only proven end/edge trim; keep spare stock for similar strip landings; reuse or trace the slotted steel retainer separately if needed. |
| `FS-STRIP-R` | Released for quote / first article | `1 cut from stock` | Same `420 L x 38 W x 8 T mm` cut piece from the shared `38 x 8 mm` stock unless the right side proves a handed or non-straight trim. | Same first-article dry-fit and retainer rule as left. |
| `BUMP-60010-LONG` | First article required | `3` | Same May 31 front-stop family: broad rounded/tapered rubber body on a metal backing/fixture with two exposed mounting ears and a flat strike area. Photo-survey nominals are `70 mm` long-family height, `110 mm` metal fixture length, `65 mm` rubber span along the hole axis, and `90 mm` metal mounting-hole pitch. | Treat the photo values as identification and first-fit dimensions to roughly the nearest `5 mm`, not manufacturing tolerances. Directly measure hole diameter, holder thread, fixture width/thickness/channel, vehicle bracket and axle strike-pad `X/Y/G/F`; make one first article before the remaining long stops. |
| `BUMP-60020-SHORT` | First article required | `1` | Exact front/right-front member of the same metal-backed family at the separately controlled `60 +/-1 mm` height; use the provisional `110 mm` fixture length, `65 mm` rubber span and `90 mm` metal-hole pitch only for first-fit screening. | The photographed `~70 mm` worn sample does not release the short height. Confirm the right-front station, hole diameter, holder thread, fixture/channel and full-bump clearance directly before manufacture or installation. |
| `BODY-LINER-FULL-WIDTH-HOLD` | Not captured yet | Hold | Possible long/full-width flat body or panel liner strips. | Do not order until the pieces are found or a vehicle station proves a continuous flat anti-squeak liner is required. |
| `EXH-HGR-90917` | Optional later hold | Hold | Teardrop exhaust hanger cushion from sample or genuine part reference. | Needs intact sample/proper tracing before production. |

## Known vs Candidate Pieces

Known current rubber pieces:

- Main body isolator pads: required, but now specified as square flat custom pads instead of circular/register bushings.
- Two-hole front-support oval pads: required by old sample/photo trail, subject to caliper confirmation.
- Axle bump stops: required if missing/decayed; May 31 front-stop photos control the active shape, and the rear/back stops are the same shape made longer. Height split is externally controlled as `70 mm` long family and `60 mm` front/right-front short family unless vehicle testing says otherwise.
- `FS-STRIP-L/R` flat strip pair: now evidenced by the May 17 loose-part photos plus installed-location photos. Treat these as custom underfloor body-support / anti-squeak strips, not generic body-mount biscuits.
- Rubber definitions must carry the 3D envelope and edge/profile control, not only a flat plan size.

Candidate or unproven pieces:

- Possible longer full-body-width flat pieces are not yet captured as orderable parts. They may be anti-squeak liners, panel-to-panel strips, packing pieces, or body support rubbers, but there is not enough evidence to assign quantity or dimensions.

## Photo Correction

The old strip rows and body-rubber rows had been mixed up with bump-stop evidence. The current split is:

- `20260502_004222_gp_PKRe5HSQ.jpg` and `20260502_004201_gp_zfUSmKJg.jpg` are strip/historical context only and are excluded from the active bump-stop gallery.
- `20260517_194143_gp_CO7MuMdA`, `20260517_194633_gp_rAjY3gjg`, and `20260517_194706_gp_twKRWGFA` are the installed-location proof for the flat strip pair.
- `20260517_193503_gp_N9nHjqXw`, `20260517_193539_gp_E0cR9I0A`, `20260517_193559_gp_NEpk1hpg`, `20260517_193612_gp_JmbfR0Tw`, and `20260517_193616_gp_1ye19BZA` are the loose-part measurement references.
- `20260528_185826_gp_FoyeBPUg` and `20260528_185833_gp_gZBjUjPg` are strip/retainer landing context only. They do not release rubber holes, slots, bonding, handed trim, or bump-stop geometry.
- `20260528_193054_gp_UFyTb44w`, `20260528_193143_gp_Cn3OWzZQ`, and `20260528_193228_gp_PLATNsFQ` are loose body-mount rubber/cup stack context only. They show round/cup fragments with tape, but the photo angles do not reopen the active single `80 x 80 x 24` square pad route.
- `20260528_193200_gp_HICSdovA` and `20260528_193253_gp_f0eQuSFA` are loose rectangular strip/block section context only. They do not release a new length, hole pattern, slot pattern, bonding, or handed trim.
- `20260531_171824_gp_HmSS2ChQ`, `20260531_171859_gp_i6bRyQKA`, `20260531_171903_gp_jNI1gfYA`, and `20260531_171935_gp_BYfhqiWg` are the usable exact front-stop measurement photos. They support provisional photo-survey nominals of `65 mm` molded-rubber span along the mounting-hole axis, `110 mm` metal backing/fixture length, `90 mm` metal mounting-hole pitch, and `70 mm` long-family sample height. These readings are to roughly the nearest `5 mm` and require direct verification before manufacture.
- `20260531_171833_gp_Vw96I7Mg` is an unrelated laptop image and is excluded from bump-stop evidence.
- `20260529_223605_gp_CklgF0cQ` and `20260529_223701_gp_wYPExcAA` are supporting removed-fixture evidence. They confirm the broad rounded body, metal-backed mounting arrangement, and central fixture/channel interface, but the usable May 31 front-stop photos are the active shape master.

## Photo Measurement Audit

Checked on 2026-05-28:

- May 17 loose strip ruler photos show the underfloor strip length at about `16.5 in`, which converts to `419 mm`. The released first-article length is therefore corrected to `420 mm`, with the existing `38 W x 8 T mm` strip section retained.
- The visible elongated slots and rust-stained channel features belong to the steel retainer or witness marks. They are not released as rubber holes; the strip remains plain unless dry-fit proves otherwise.
- May 28 loose body-mount/cup photos were checked against the current body-pad design. They add useful stack context, but no reliable new OD/height dimension replaces the active single `80 x 80 x 24` square first article.
- May 28 loose rectangular rubber close-ups support only the strip/section context. The active strip design remains the plain `420 x 38 x 8 mm` first article with no holes or slots by default.
- May 31 front-stop photos now control the active bump-stop shape. They replace the old strip/photo mix and the prior flat-back-plate-only placeholder. May 29 removed-fixture photos remain supporting construction evidence only. The external height controls remain `70 mm` long-family and `60 mm` front/right-front short until vehicle testing says otherwise.
- May 2 body-pad/cup photos support the current pad thickness range and washer/cup context, but do not prove a round rubber outside profile. The single square `80 x 80 x 24` body pad remains the active Longman route and stays separate from bump-stop evidence.

## External Control Notes

Open-catalog checks support custom recreation of the strip pair rather than substitution from a standard body-mount kit:

- ToyotaPartsDeal `Cab Mounting & Body Mounting` for a 1978 Land Cruiser exposes the normal cushion/spacer/shim/holder rows, but not an open-catalog equivalent to this short underfloor strip.
- SOR `Body Mounts` likewise focuses on the standard large/small body-mount families and hardware.
- Aqualu's early-frame note also reinforces that the common body-mount discussion is about separate mount pads, not this strip-retainer arrangement.

Use those sources only as context. The actual released strip geometry is controlled by the May 17 loose-part and installed-location photos plus the original samples.

## Separated Hardware

The following remain required for body-mount stack control but are excluded from the Longman rubber order:

- Body-mount cup/seat washers.
- Body-mount crush sleeves.
- Body shims/spacer plates.
- Bolts, nuts, weld nuts, repair tabs, and captive-thread repairs.

Inspect the existing washers/cups separately. Reuse only if they are flat where required, not thinned, not cracked, and still fit the rubber/sleeve stack. If new ones are needed, order them as steel hardware, not as rubber.

### Body-Mount Sleeve Spec

The sleeve release is Toyota `90560-12009`, listed in Toyota Heritage/parts data as the body-mount spacer with `L=48.1 mm` on late 40-series body mounts. Open kit instructions also show the standard body-mount pack uses six steel tubes.

The only direct OD evidence found so far is a physical field measurement on IH8MUD: all six original crush tubes were identified as Toyota `90560-12009`; the Toyota tube was described as a bit over `17 mm` OD, the lower Toyota bushing centre hole as `18 mm`, and a `16 mm` aftermarket tube as smaller/sloppier.

Use this as the exact best spec:

- Sleeve part: Toyota `90560-12009` style body-mount spacer, qty `6`.
- Sleeve length: `48.1 mm`.
- Sleeve ID: M10 clearance, `10.8-11.0 mm` if locally fabricated.
- Sleeve OD: copy a genuine/old `90560-12009`; do not choose arbitrary tube stock.
- Rubber bore: `18.0 mm` through for the single `80 x 80 x 24` body pad.
- Reject: `16 mm` OD tube unless a dry-fit proves the stack cannot wander.
- Local fabrication route: machine one sample tube from old/OE dimensions, dry-fit with the `18.0 mm` rubber bore and cup/washer stack, then release the other five.

The open checks are local-fit checks only. They do not ask Longman or the machinist
to invent a dimension: the released spec remains Toyota `90560-12009`, `48.1 mm`
long, `18.0 mm` rubber bore, and OE/old-sleeve OD copied if a local sleeve has to
be made.

## Measurements To Collect

These measurements are not asking for the rubber dimensions again; those are already in the spec above. They are the vehicle-fit checks needed to prevent a correct rubber part being installed in the wrong station or wrong stack.

### Main Body Isolator Stations

For every station:

- Label station and side.
- Tub-side landing face photo with ruler.
- Chassis-side landing face photo with ruler.
- Maximum flat footprint before bends, seams, weld lips, repairs, or rust-thinned edges.
- Desired free height or best old-sample free height.
- Bolt size and captive nut or through-bolt arrangement.
- Old crush-sleeve OD/ID if available, only to confirm it matches the Toyota `90560-12009` family or to give a local machinist the OD to copy.
- Confirm the released `18.0 mm` rubber bore clears the sleeve without allowing the stack to wander.
- Whether the released square `80 x 80` pad fits, or which exact corners/edges need trimming.

### Front-Support Oval Pads

- Top photo of each old oval pad with ruler.
- Length, width, thickness.
- Hole diameter and hole centre-to-centre.
- Photo/measurement of insert, boss, washer imprint, or relief.
- Confirmation whether the rectangular relief is functional or old deformation.

### Underfloor Body-Support Strip Pair

- Order `2 m` of `38 x 8 mm` strip stock and cut the released `420 x 38 x 8 mm` first articles from that stock after dry-fit because the landing path may not be perfectly straight.
- Confirm only the local handed end trim, if any, during dry-fit.
- Hole or slot geometry belongs to the steel retainer, not automatically to the rubber.
- Reuse or trace the original slotted steel retainers if they are not serviceable.

### Long / Full-Width Flat Liner Holds

If longer flat pieces are found:

- Location photo showing full installed path.
- Full-length photo with tape measure end to end.
- Close photos of both ends, holes, slots, notches, and witness/contact marks.
- Quantity, side, handedness, and whether the part is full body width.
- Length, width at several points, thickness, hole/slot size, hole centre distances, and edge radii.
- Whether it was loose, bonded, clipped, trapped under bolts, or glued.
- Evidence of function: isolator, anti-squeak liner, seal, or packing strip.

### Bump Stops

For front-left, front-right, rear-left, and rear-right:

- Wide station photo.
- Square-on bracket photo with ruler/caliper.
- Bolt/stud/retainer feature photo with centre-to-centre measurement.
- Side photo showing mount face, axle strike pad, and current gap.
- Loaded ride-height gap after suspension is fitted.
- Near-full-bump measurement confirming the stop contacts before shocks, tyres, springs, shackles, brake hoses, or metal hard limits.

Record:

| ID | Measurement | Use |
| --- | --- | --- |
| `BL` | Metal fixture overall length (`~110 mm` from the photo survey) | Fixture envelope and bracket landing |
| `BW` | Rubber body / fixture landing width | Rubber body width and central fixture/channel clearance |
| `RB` | Molded-rubber span along the mounting-hole axis (`~65 mm` from the photo survey) | Rubber body identification and mould-envelope screening |
| `P` | Metal fixture-ear mounting-hole pitch centre-to-centre (`~90 mm` from the photo survey) | Fixture alignment; verify directly before drilling or manufacture |
| `D` | Metal fixture-ear hole diameter and internally threaded holder size/pitch | Fastener control; not released by the photographs |
| `X/Y` | Strike-pad centre offset from fixture/bracket features | Contact face location |
| `G` | Loaded stop gap | Ride-height clearance |
| `F` | Near-full-bump clearance | Confirms stop acts before hard limits |

## Acceptance

- Longman provides compound family and Shore A target.
- Body/front-support rubber averages Shore A `55-65`.
- Bump-stop rubber averages Shore A `65-75`, or PU `75-85` only if the May 31 metal-backed fixture-ear mounting layout, central fixture/channel interface, rebound recovery, and progressive shape are correct.
- Faces on body pads are flat and parallel within `0.5 mm`.
- Holes are clean, not burnt or torn.
- Bump-stop first articles pass 50 percent compression without cracking, retention failure, or permanent collapse; after 30 minutes unloaded, height recovers to at least 90 percent.
- Parts are bagged and labeled by ID and side/station.

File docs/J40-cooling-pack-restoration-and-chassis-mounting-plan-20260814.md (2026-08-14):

# J40 Cooling-Pack Restoration and Chassis-Mounting Plan

> **SUPERSEDED FOR THE NATURALLY ASPIRATED BUILD.** This document preserves the former Rev L turbo/K0/twin-front-fan plan for traceability. Do not use it for fabrication or purchasing. Use [J40 Naturally Aspirated Cooling + A/C Restoration Guide — Rev M](J40-naturally-aspirated-cooling-pack-restoration-guide-rev-m-20260814.md), which removes K0 and the second front fan while retaining the large rear radiator puller.

**Issue:** 14 August 2026
**Status:** **SUPERSEDED HISTORICAL PLAN — NOT FOR FABRICATION OR PURCHASING**
**Applies to:** R0 engine radiator, C0 A/C condenser, G0 stone guard, FL large rear electric fan/shroud, FS small front-fan candidate, the existing chassis support arms, and all fittings needed to mount them correctly
**Controlled basis:** [Rev L cooling-pack specification](J40-photo-measured-retained-cooling-pack-specification-rev-l.md) and [Rev L complete parts list](j40-rev-l-complete-oem-donor-parts-list-20260803.md)

Rev L supersedes the earlier Rev K and older radiator-workstream layouts. In particular, FL is an **electric rear puller**, not a mechanical fan, and all photo-derived dimensions remain mock-up values until checked on the real vehicle.

## 1. Intended result

Restore the retained parts to a clean, straight and coordinated OEM-style finish without sacrificing heat transfer, pressure integrity, isolation or service access:

- straight, clean and uniformly presented heat-exchanger faces;
- deep satin or restrained semi-gloss black on visible brackets, shrouds and guard;
- matching bright-zinc automotive fasteners, aligned washers and neat witness marks;
- fresh black EPDM rubbers, hoses, seals, edge trim and anti-chafe material;
- tidy sealed fan wiring in black loom with properly spaced rubber-lined P-clips;
- no overspray, loose mesh, exposed rust, mismatched hardware, unsupported pipes or visible improvised mounting legs.

“Gleaming” means meticulous and corrosion-free, not heavy gloss paint on cores. Thick paint, powder coat or cosmetic filler must never be applied to radiator or condenser fins, soldered seams, plastic fan blades, motor vents, electrical labels, hose lands, sealing faces or rubber isolators.

The controlled finished air path remains:

**grille → G0 stone guard → two equal front pushers → reserved low-centred K0 intercooler position → C0 condenser → R0 radiator → sealed FL rear puller/shroud → engine**

K0 is a new component rather than a restoration item, but its full dummy, clearances and independent mounts must be represented during every pack dry fit.

## 2. Retain, restore or replace decision

| Item | Starting decision | Release condition |
| --- | --- | --- |
| **R0 copper/brass radiator** | Restore original tanks, filler, necks, rails, ears and lower locators where sound; the budget and programme should assume a recore because the photographed core is tired and damaged. | Retain or copy each original piece only after inspection; completed unit must pass pressure, flow and dimensional checks. |
| **C0 aluminium A/C condenser** | Restore the full-width condenser, pipes and brackets if serviceable. The old receiver/drier remains a geometry sample only. | Pass external-fin, flush/contamination and specialist pressure/leak checks. Fit a new compatible drier and new disturbed-joint seals. |
| **G0 stone guard** | Restore the frame; straighten or renew the expanded-mesh insert to the original open-area pattern. | Frame is square, mesh has no loose/broken strands, open area is preserved, and the complete guard is independently removable. |
| **FL large fan and full shroud** | Clean and restore only after its motor, blade, shroud and electrical performance pass. | Correct engineward pull, sound mounts/blade/shroud, acceptable start/run current, no bearing play or rubbing, and released installed airflow. |
| **FS small front fan** | Treat as the master sample and candidate, not an automatically accepted final part. | Use with one exact tested mate only if the complete pair fits and matches. Otherwise fit two identical replacement pushers and keep FS as a tested spare. |
| **Existing radiator arms/uprights** | Inspect and retain the July-welded structure if geometry and weld quality pass. | Weld/HAZ, height, plane, hole alignment, clearance, proof load and coating restoration all pass. |
| **Old added radiator leg** | Record its geometry, then remove it from the service configuration. | It is a historical workaround only. Do not reproduce it on R0 or use it to carry radiator weight. |

## 3. Stage 0 — evidence and measurements before stripping

Do this with R0, C0, G0, FL, FS and the vehicle physically together.

1. Attach durable tags `R0`, `C0`, `G0`, `FL` and `FS`; mark orientation, front/rear, left/right and vehicle centreline.
2. Photograph every face, label, plug, pipe, bracket, crack, solder joint and mounting point with a scale before dismantling.
3. Cap every open coolant and refrigerant connection immediately. Keep C0 dry and clean internally.
4. Record R0 true outside width/depth, cap height, active face, neck positions and diameters, drain, ear coordinates and lower-locator geometry.
5. Make one rigid **B0** template that captures both original upper chassis-hole diameters and XYZ centres.
6. Make one rigid **S0** template that captures both R0 lower locators, saddle centres, pin diameters and required installed rubber height.
7. Record the lower-crossmember clear span and end interfaces as **L0**, and weigh the filled and capped radiator as **MR**.
8. Record C0 complete width, height and depth including tabs, pipes, drier/manifold, ports, cable/pipe bends and A/C-tool sweep.
9. Record FL and FS complete envelopes, including every frame tab, guard, motor, plug and required cable bend. Blade/ring diameter alone is not a fit dimension.
10. Record the clear vehicle width at top, middle and bottom, both depth zones, bonnet/latch/grille/bumper envelopes, engine movement, hoses, belts, wiring and all service-tool sweeps.

No final ear, cradle, condenser bracket, fan carrier or guard fitting may be drilled, welded or coated until these measurements are on a dated drawing and the opaque 1:1 stack passes.

## 4. Component restoration work packages

### 4.1 R0 — original copper/brass engine radiator

**Specialist:** experienced copper/brass radiator shop.

1. Carry out baseline pressure and flow tests and provide written results before cosmetic work.
2. Inspect the top and bottom tanks, header joints, filler neck and cap seat, hose necks, overflow nipple, drain, side rails, ears and lower locators for cracking, dezincification, thinning, distortion and failed solder.
3. Use controlled radiator-shop chemical cleaning and gentle external cleaning. Do not abrasive-blast the assembled core or use aggressive pressure that folds fins.
4. Plan and quote a new core compatible with the Rev L 50 °C/150 bhp duty. The system release target is at least 115 kW continuous and 130 kW for 10 minutes; the actual core construction must be agreed from the real unit and test data, not a photograph.
5. Jig the retained tanks, rails, ears and locators before desoldering. Recore squarely without changing the neck map, cap height, drain access, FL sealing face or B0/S0 relationships.
6. Repair or reproduce only sound original ears and locators. After recording it, remove the added support leg/workaround without damaging the tank or rail; do not copy it.
7. Dress hose lands smooth and round, test the cap seat and drain, and fit a new approved-pressure cap only after the system pressure is released.
8. Repeat pressure and flow tests after all soldering and again after final external finishing if the coating process adds heat.
9. Mask the filler throat/cap seat, neck interiors and clamp lands, drain seat/threads, identification marks, rubber contacts and all fastener interfaces.
10. Apply only a thin radiator-shop heat-exchanger coating. Use an even satin/semi-gloss black on tanks and side rails, with the minimum compatible coating on the core. No powder coat, thick primer or body filler on the heat exchanger.

**R0 visual acceptance:** square tanks and rails; straight uniform core; clean soldering; no green residue or active corrosion; no runs or blocked fins; crisp masking; new cap, hoses and clamps; no improvised leg.

### 4.2 C0 — retained full-face A/C condenser

**Specialist:** automotive A/C shop familiar with aluminium condensers and the actual refrigerant/oil system.

1. Keep the ports capped. Identify refrigerant, oil, every fitting and seal type from the real system before opening or flushing.
2. Inspect manifolds, tubes, brackets, pipe unions, service access and every fin row. Reject the unit if corrosion, impact or contamination cannot be safely repaired.
3. Externally clean with condenser-safe neutral chemistry and low-pressure rinsing/air in the fin direction. Carefully comb folded fins without puncturing tubes.
4. Flush only by an approved A/C procedure. Never use oxygen, shop air or an unapproved solvent.
5. Pressure/leak-test with dry nitrogen or approved forming gas at the system/service-manual test pressure. Do not guess a pressure from the photographs.
6. Straighten or repair original tabs in a jig without loading the manifold or core. Any heat repair to aluminium stays with the specialist.
7. Use the photographed old drier/manifold to control packaging only. Fit a new compatible receiver/drier or service element, new HNBR O-rings/seals and new service caps at final assembly; keep the new drier sealed until installation.
8. Preserve the full face and all required pipe/tool sweeps. Do not crop C0, hang K0 from it or use its body as the front-fan carrier.
9. Leave sound natural aluminium clean or renew only the original-type ultra-thin heat-exchanger coating. Finish separate steel brackets in the black bracket system below. Do not powder-coat the core or bridge fins with paint.

**C0 visual acceptance:** clean and uniformly straight face; capped clean ports; crisp restored tabs; no bent pipe caused by mounting; new drier/seals bagged and identified; written leak-test result.

### 4.3 G0 — removable expanded-mesh stone guard

**Specialist:** fabricator/coater after mock-up release.

1. Photograph and jig the original frame, hole positions, offsets and curvature before straightening.
2. Degrease, remove the mesh if practical, strip loose coating and corrosion, and inspect the frame and welds for thinning or cracks.
3. Square the frame. Replace the ragged or broken mesh insert if straightening would leave loose strands; match the original mesh pitch, wire/strand size and open area.
4. Grind only sharp projections and untidy repair spatter. Do not thin the frame or close its drainage path.
5. Blast or mechanically prepare **the steel guard only**, not any heat exchanger. Apply epoxy primer followed by a durable 2K satin/semi-gloss black topcoat. Keep the mesh coating thin enough that apertures do not bridge.
6. Add neat black edge trim or anti-chafe material where the released assembly could touch an adjacent carrier. Use fresh rubber-faced stand-offs at the released mounting points.
7. Mount it with accessible captive or locking hardware on its independent carrier. It must come off without removing R0 or discharging the A/C.

**G0 visual acceptance:** square, taut and centred mesh; uniform open area; no sharp/broken strands; clean black finish on all visible edges; identical fasteners; no contact with fins or fan guards.

### 4.4 FL — large rear electric puller and full shroud

**Specialists:** auto electrician plus plastic/metal repairer as required.

1. Before dismantling, record manufacturer, part number, voltage, plug, polarity, rotation and airflow direction.
2. Check blade roots, blade runout, motor shaft/end play, bearing noise, guard clearance, shroud cracks and all mounting tabs. Reject a blade or shroud with unsafe cracking around the motor or support points.
3. Bench-record start current, stabilised current and voltage at the motor. Confirm that the installed orientation pulls air through R0 toward the engine in the blade/shroud’s designed direction.
4. Wash plastic with a plastic-safe detergent and soft brushes. Do not solvent-soak, blast or paint the blades, motor, vents, plug, label or rubber mounts.
5. Plastic-weld minor non-critical shroud cracks with compatible material and reinforcement on the hidden side. Replace the shroud if motor or load-bearing mounts cannot be restored reliably.
6. Clean and repaint separate steel brackets with epoxy primer and 2K black topcoat. Restore faded plastic only with a compatible thin plastic coating after adhesion testing; otherwise leave it clean and original.
7. Fit sound connector shells with new correctly crimped terminals and seals, new cable/earth sized from the measured current, black loom and proper strain relief.
8. Attach the full shroud through an independent removable support arrangement that does not make the radiator fins, tanks or soldered seams carry its weight. Seal the shroud perimeter to the released R0 face with closed-cell EPDM without covering fins, drainage or service points.

**FL visual acceptance:** clean matched-black appearance; no wobble, rub or vibration; protected label; sealed plug; tidy loom; removable shroud; documented current, direction and installed-airflow result.

### 4.5 FS — small front-fan candidate and its matching pair

1. Perform the same label, blade, bearing, current, polarity and airflow checks as FL before spending on cosmetics.
2. Take the complete FS module to the donor supplier. A retained FS plus one mate is permitted only when frame, tabs, guard, motor, blade, plug, label/part number, depth, current and direction truly match.
3. If an exact mate is unavailable or either fan fails, use two identical Toyota/Denso replacement modules and retain the tested FS as a labelled spare.
4. Restore the accepted pair together so both guards, shrouds, grommets, connectors and visible finish match. Do not cut either guard or mix different fan designs.
5. Fit both to one centred, removable carrier with donor-pattern rubber grommets/shoulder sleeves. The pair, carrier, plugs and cable bends must remain inside the released front-view envelope and must not hang from G0 or C0.
6. Give each front fan its own sealed relay, covered fuse and earth branch. Route equal-looking looms symmetrically and P-clip them clear of fins and service paths.

**Pair geometry acceptance:** preferred 10 mm centre gap; fan centres level and pair midpoint on vehicle centreline within 2 mm; equal positive side margins; both push grille-to-engine; no cropped guards or strained plugs.

## 5. Chassis-mount system and fittings

The R0 load path is mandatory:

**R0 lower locators → two new rubber saddles → full-width lower crossmember → gusseted/removable end connections → both structural side uprights**

The lower saddles carry all filled-radiator weight. The two upper fittings only locate R0 fore/aft and laterally.

| Ref | Qty | Fitting / fabricated item | Requirement |
| --- | ---: | --- | --- |
| **X0** | 1 | Full-width lower crossmember | Start a fixture with 40 × 40 × 3 mm mild-steel SHS only if clear span is no more than 700 mm and MR is no more than 35 kg; otherwise recalculate. Provide drainage and removable/gusseted attachment to both uprights. |
| **X1** | 2 | Lower saddle seats | Level, reinforced seats fixed to X0 at the S0 centres. Their faces support the rubber saddles, not a tank or seam. |
| **R1** | 2 | New Toyota/J40-pattern lower rubber saddles | Sample-match locator diameter, cup depth, installed height, load area and seat. Both pins must sit fully without metal contact. |
| **T0** | 2 | Short removable upper radiator ears/stays | Drill from B0 only after R0 rests naturally on both R1 saddles. No slotting and no forced alignment. Finish as removable black brackets. |
| **R2** | 2 sets | Upper isolation hardware | New automotive EPDM bush, steel crush sleeve, large washers, zinc-plated class 8.8 bolt and locking nut at each original inward-facing chassis hole. Sleeve length controls compression; the bolt must not crush the rubber solid. |
| **A3** | To all released tabs | C0 isolator sets | New Toyota/Denso-pattern grommets or automotive EPDM, shoulder/crush sleeves, washers and removable locking fasteners. C0 has independent brackets and no metal-to-metal core/manifold load. |
| **F0** | 1 carrier set | Centred twin-front-fan carrier | Independent removable carrier with matched fan grommets/shoulder sleeves, symmetric holes and provisions for sealed plugs/loom. No through-core ties. |
| **FL0** | 1 support/seal set | Rear shroud attachment | Independent removable support plus closed-cell EPDM perimeter seal. No weight on fins, tanks, necks or solder seams. |
| **G1** | To released holes | Guard stand-offs and fasteners | Rubber-faced stand-offs/edge trim with captive or locking fasteners on the released independent carrier. No self-tappers into structural supports and no new chassis holes. |
| **M2** | 1 complete set | General hardware | New, matching zinc-plated class 8.8 bolts, large washers, locking nuts, correctly sized crush sleeves/spacers and any retained-component fasteners. Final diameters, pitches and lengths come from the released drawings. |
| **M3** | As measured | Sealing and protection | Closed-cell automotive EPDM foam, edge trim, anti-chafe strip, heat sleeve, grommets and rubber-lined metal P-clips. Keep all active fins, drainage and service points open. |

### Fastener workmanship standard

- Use the original two upper chassis holes and released existing pickup points. Do not slot, ream or drill new chassis holes and do not pull R0 into alignment with bolts.
- Do not use structural self-tappers, through-core plastic ties, ungraded bolts, stacked loose washers as spacers, or a fastener compressed through rubber without a crush/shoulder sleeve.
- Put bolt heads and washers in a consistent visible orientation; use one fastener finish and head style where practical.
- Set final torque from the released bolt size, grade, coating and joint design. Record it on the drawing, apply witness marks after inspection, and use the specified locking method rather than unrecorded thread compounds.
- Keep fasteners accessible with normal tools and arrange the pack so G0, fans, C0, R0 and FL can be removed in a logical sequence.

## 6. Existing chassis-arm and lower-cradle restoration

1. Clean the two welded radiator arms/uprights sufficiently to expose both weld toes, ends and heat-affected zones.
2. Inspect weld continuity, undercut, porosity, cracking and incomplete fusion; check both arms for matching height, plane, angle, hole alignment and clearance. Use non-destructive crack checking where visual findings are doubtful.
3. Do not grind structural welds flat for appearance. Repair only after geometry and load path are agreed by the competent fabricator.
4. Fit X0, X1 and temporary saddles; perform the complete bare-metal dry fit and proof load before any final coating.
5. Remove spatter and sharp edges, clear drains and protect all threads/mating faces.
6. Degrease and mechanically prepare sound steel; apply compatible epoxy primer. Match welded chassis pieces to the project chassis/Raptor top-protection system and finish removable visible carriers/brackets in durable 2K satin/semi-gloss black.
7. After cure, open every masked hole, confirm drains, apply cavity protection to eligible closed sections, then install fresh rubber and new hardware. Never coat rubber or trap it against wet paint.

## 7. Mandatory bare-metal dry fit before paint

Assemble an opaque full-size stack with the actual parts and a complete K0 dummy. The fit must represent the grille, bumper, bonnet/latch, pipes, hoses, wiring, fuse-box lid, tools and engine movement.

- R0 must sit naturally and level on both lower saddles with its top fittings loose; no tank, seam or fin may touch a support.
- Make and drill T0 only in that natural position. Tightening the top fittings must not lift R0 or move a lower locator in its saddle.
- Maintain the released separation between C0 and R0; Rev L uses 10–15 mm as the upper-zone fixture allowance.
- Prove cap removal, drain operation, upper/lower/overflow hose installation, A/C union and drier access, both fan plugs, fuse-lid sweep, belt/tool access and a credible core-removal path.
- Prove G0 removal without touching fins and prove each fan/condenser/shroud support is independent.
- Check all hoses and wires through the full engine-movement envelope. Nothing may rub a blade, belt, fin edge, bonnet/latch or sharp bracket.
- Verify that the two complete front fans, including plugs and cable bends, are centred and inside the released aperture.
- Seal bypass paths in the mock-up but do not block fins, drainage or the bonnet/latch mechanism.

Before paint, fill and cap R0, record MR, then proof-load X0/X1 at the two saddle centres to **twice MR for 10 minutes**. Pass requires no permanent set, cracked weld, loosened fastener, saddle movement or upright distortion.

## 8. Final assembly sequence

1. Install the cured lower crossmember, saddle seats and two new R1 saddles; verify level and S0 centres.
2. Lower the finished R0 into both saddles without scraping paint or loading a neck. Confirm full pin engagement.
3. Install both T0/R2 upper locating sets loose, settle the unit, then tighten to the released torque without compressing the isolation beyond the sleeves.
4. Install the independently supported C0 with new A3 isolators, leaving the new drier sealed until the A/C specialist completes the circuit.
5. Install the released K0 package when available, then the centred twin-fan carrier and G0. Maintain all dry-fit gaps.
6. Install FL and its perimeter seal at the rear. Hand-turn the blade and recheck all engine/hoses/tool clearances.
7. Fit new moulded upper, lower and overflow hoses, new constant-tension clamps, the approved cap, 2H thermostat/seal and compatible coolant service pack. Old hoses and the formed old pipe are patterns only where the replacement-pipe workstream applies.
8. Complete three independent fan branches with sealed relays, covered fuses, correct cable, grounds, terminals and strain relief. Keep every live stud covered and cable exits down/rear.
9. Complete the A/C with new drier/seals, evacuate, leak-test and recharge by the identified refrigerant mass and oil procedure.
10. Torque-check, witness-mark, clean fingerprints/residue, align clamps and P-clips, and photograph the finished assembly from grille and engine sides.

## 9. Release gates and acceptance record

### Gate A — specialist component release

- [ ] R0 pre-work and post-work pressure/flow results recorded.
- [ ] R0 retained-part/recore decision and final core construction recorded.
- [ ] C0 flush/contamination decision and nitrogen/forming-gas leak result recorded.
- [ ] New receiver/drier and all disturbed-joint seals identified.
- [ ] FL and both accepted front fans have label, polarity, direction, start current, stable current and voltage recorded.

### Gate B — structure and fit release

- [ ] B0, S0, L0, MR and full component/vehicle envelopes recorded on a dated drawing.
- [ ] Existing arm welds/HAZ and side-to-side geometry accepted.
- [ ] Opaque 1:1 stack passes bonnet, grille, bumper, latch, pipe, hose, wiring, service and engine-movement checks.
- [ ] Lower cradle passes the twice-MR/10-minute proof test before coating.
- [ ] Lower saddles carry the radiator; top fittings locate only and are neutral when loosened.
- [ ] Every heat exchanger, fan and guard has its own removable support; no through-core ties or improvised leg remain.

### Gate C — finish release

- [ ] No active rust, bare steel, coating run, overspray, bridged mesh aperture or blocked fin row.
- [ ] Heat-exchanger coating is thin and masking lines are clean.
- [ ] Rubber parts, labels, sealing faces, hose lands, connectors, motor vents and threads are paint-free.
- [ ] Visible fasteners match, wiring/hoses are aligned and supported, and all live terminals are covered.
- [ ] All drains and service/removal paths remain open after final assembly.

### Gate D — installed performance release

- [ ] Cooling and A/C circuits are leak-free through cold, hot-idle and heat-soak checks.
- [ ] FL pulls engineward; both front fans push engineward; no blade rub or abnormal vibration occurs.
- [ ] Complete installed stack delivers at least 3,000 m³/h at 13.5 V at fan terminals, with 3,300 m³/h preferred.
- [ ] Fan voltage drop, branch current, fuse/relay/cable temperature and charging performance pass at hot idle with normal loads.
- [ ] Instrumented Rev L 50 °C/150 bhp thermal test passes: R0 heat rejection, coolant stability, post-CAC IAT, charge pressure drop and A/C high-side stability meet the controlled criteria.
- [ ] Final inspection after the first full heat cycle finds no leaks, settling, witness-mark movement, hose strain, rubbing or loose fastener; repeat after the first loaded road test.

## 10. Shop handoff package

Give the shops the actual parts plus:

1. this restoration plan;
2. the controlled Rev L specification and parts list;
3. the B0/S0 rigid templates and dated measurement drawing;
4. pre-work photo sheets and the required acceptance checklist;
5. written instructions that all fabrication, drilling, proof testing and dry fit happen **before** final paint;
6. labelled bags for every original clip, bracket and fastener retained only as a pattern.

No part is accepted merely because it looks newly painted. A gleaming finish is the final layer over a pressure-tight, electrically proven, rubber-isolated and naturally aligned cooling pack.

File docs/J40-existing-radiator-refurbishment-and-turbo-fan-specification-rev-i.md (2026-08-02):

# J40 Original-Radiator Refurbishment + Turbo-Fan Cooling Pack

**Fabricator issue Rev I — 2 August 2026**<br>
**Design ambient:** 50 °C<br>
**Engine basis:** Toyota 2H with planned turbo ceiling of 150 bhp / 112 kW<br>
**Fit master:** the actual removed copper/brass radiator, identified below as **R0**

> **Take R0 to the radiator shop. Do not fabricate the radiator from photographs or old drawing dimensions.** Measure it before dismantling, fit a new core, and preserve—or exactly copy—its tanks, coolant-neck positions, filler/cap seat, overflow, drain, side rails, upper mounting ears and lower locators.

The earlier `530 × 435 × 64 mm` radiator concept is no longer a fit-release dimension. The physical R0 sample and a rigid 1:1 fixture made from the vehicle mounting points now control fit.

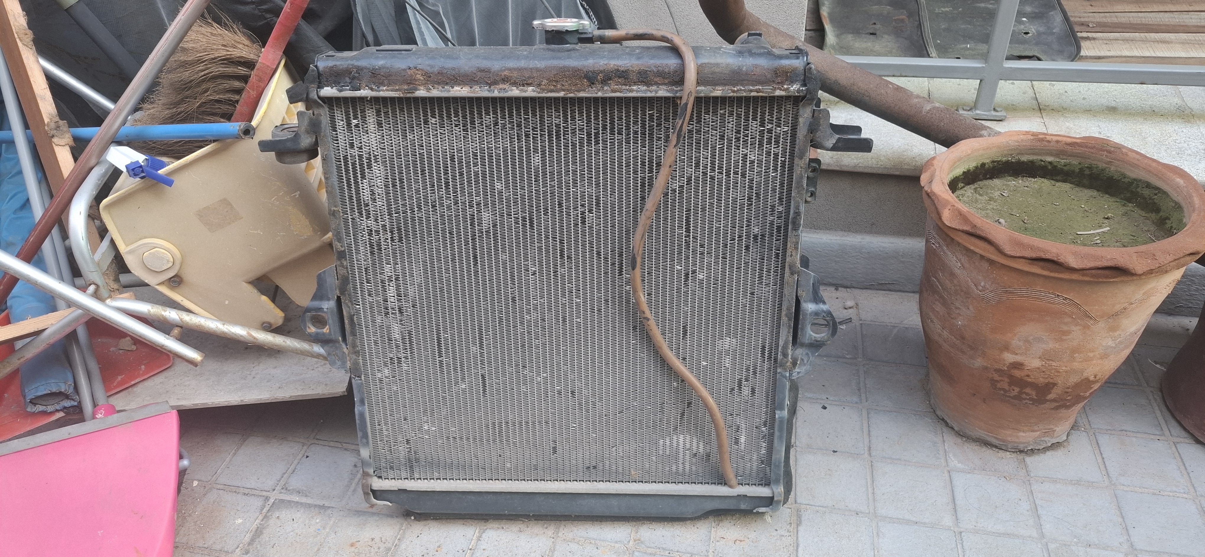
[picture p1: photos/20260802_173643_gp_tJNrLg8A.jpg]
Actual removed R0 engine radiator


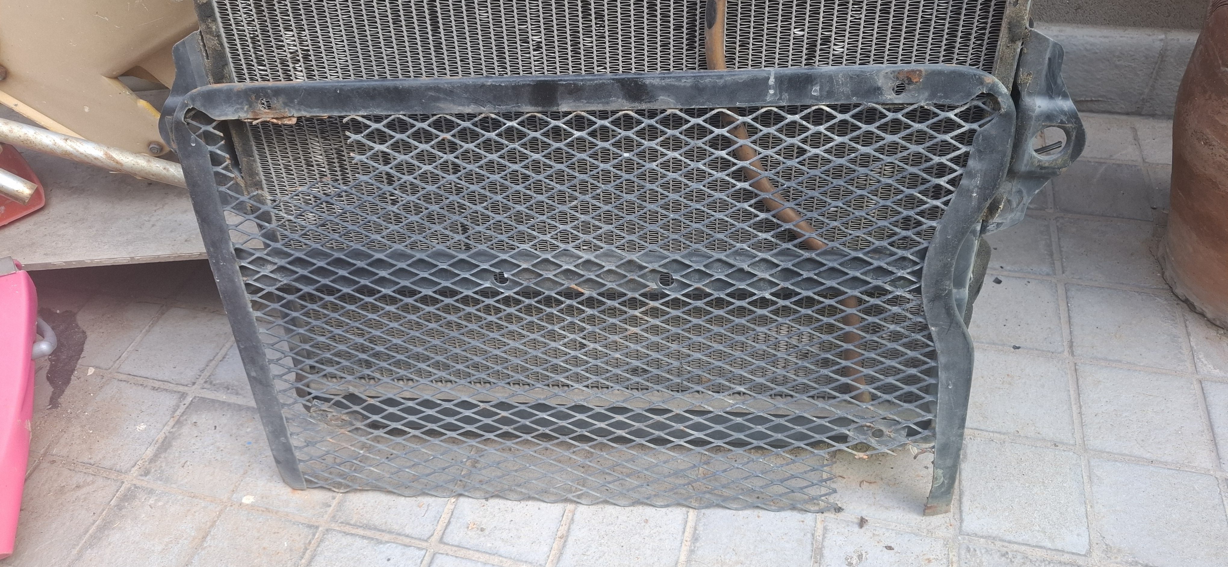
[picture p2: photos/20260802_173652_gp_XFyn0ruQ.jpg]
Actual removable expanded-mesh stone guard


## 1. Simple description for the workshop

Build one compact cooling pack in this order:

**grille → removable stone guard → two centred electric pusher fans → charge-air cooler → A/C condenser → recored R0 radiator → full-face shroud → large 2H mechanical fan → engine**

There are exactly:

- three heat exchangers: charge-air cooler, A/C condenser and engine radiator;
- two matched front Toyota/Denso electric pusher fans; and
- one large rear Toyota 2H engine-driven mechanical puller.

Fan 2 is called the **turbo fan** because high intake-air temperature or boost is its lead electrical trigger. It blows outside air through the charge-air core and the shared cooling stack. It does **not** blow directly onto the turbocharger housing, and it is not a fourth fan.

Both front fans are horizontally centred on the vehicle. Their hubs are equally spaced about the vehicle centreline and sit at the same height.

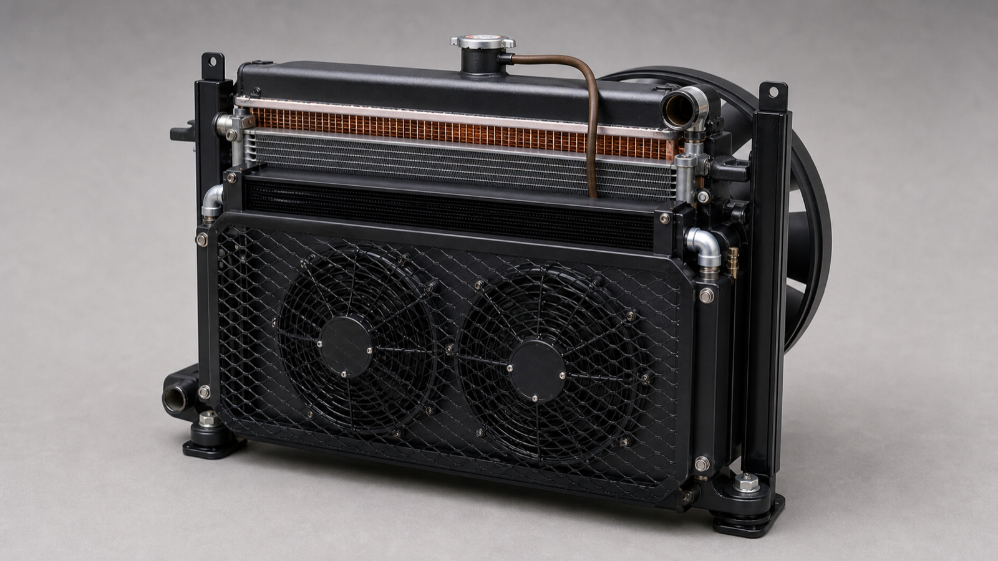
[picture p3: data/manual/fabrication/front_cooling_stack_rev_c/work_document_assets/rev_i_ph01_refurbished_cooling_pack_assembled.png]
Opaque assembled cooling-pack concept


## 2. Parts retained, rebuilt or added

| Part | Quantity | Work required |
| --- | ---: | --- |
| Original R0 engine radiator | 1 | Dismantle, inspect and recore. Retain exact vehicle interfaces. Old core is rejected. |
| Original expanded-mesh stone guard | 1 | Clean and repair, or reproduce its frame. Keep independently removable and at least 70% open area. |
| Charge-air cooler | 1 | Add a slim core with exactly two 57 mm beaded air ports. |
| A/C condenser | 1 | The thin aluminium archive sample is the A/C condenser, not the engine radiator. Reuse only after identification, pressure test, flush and fit check; otherwise use a checked replacement. |
| Front electric pusher fans | 2 | Use a matched pair of Toyota/Denso Prado 120 / GX470 nominal 248 mm fans, centrally mounted. |
| Rear mechanical puller | 1 | Retain the Toyota 2H engine-driven fan behind a full-face shroud. |
| Relay box | 1 | Closed/sealed box on its own high/rear bracket, inside the available width. |
| MIDI-fuse box | 1 | Closed box with cover on a separate high/rear bracket, inside the available width. |

## 3. Radiator-shop work on R0

1. Tag and photograph R0 before dismantling.
2. Record every field in the measurement sheet in section 4.
3. Strip paint and scale, dismantle, and chemically clean it.
4. Pressure- and flow-check the top and bottom tanks, seams, filler neck, both large coolant necks, overflow, drain, side rails and mounting ears.
5. Reject any pitted, cracked or thinned tank, neck, seam, rail or ear. If an original piece is unsafe, reproduce its external geometry from R0 before discarding it.
6. Fit a new heavy-duty, high-efficiency copper/brass core on the original header/tank footprint. A four-row core is preferred only if depth, airflow and fan clearances pass; verified performance controls acceptance.
7. Preserve the original coolant-neck centres, angles and outside diameters. Preserve the filler/cap position, cap-seat type, overflow route and drain position.
8. Use only a thin fin-safe black coating. Do not bury fins or soldered joints in thick paint.
9. Pressure-test at a shop pressure agreed from the actual engine system and cap neck. Do not guess the cap rating.
10. Flow-test, hot-recirculation test and leak-test after final soldering. Record results.

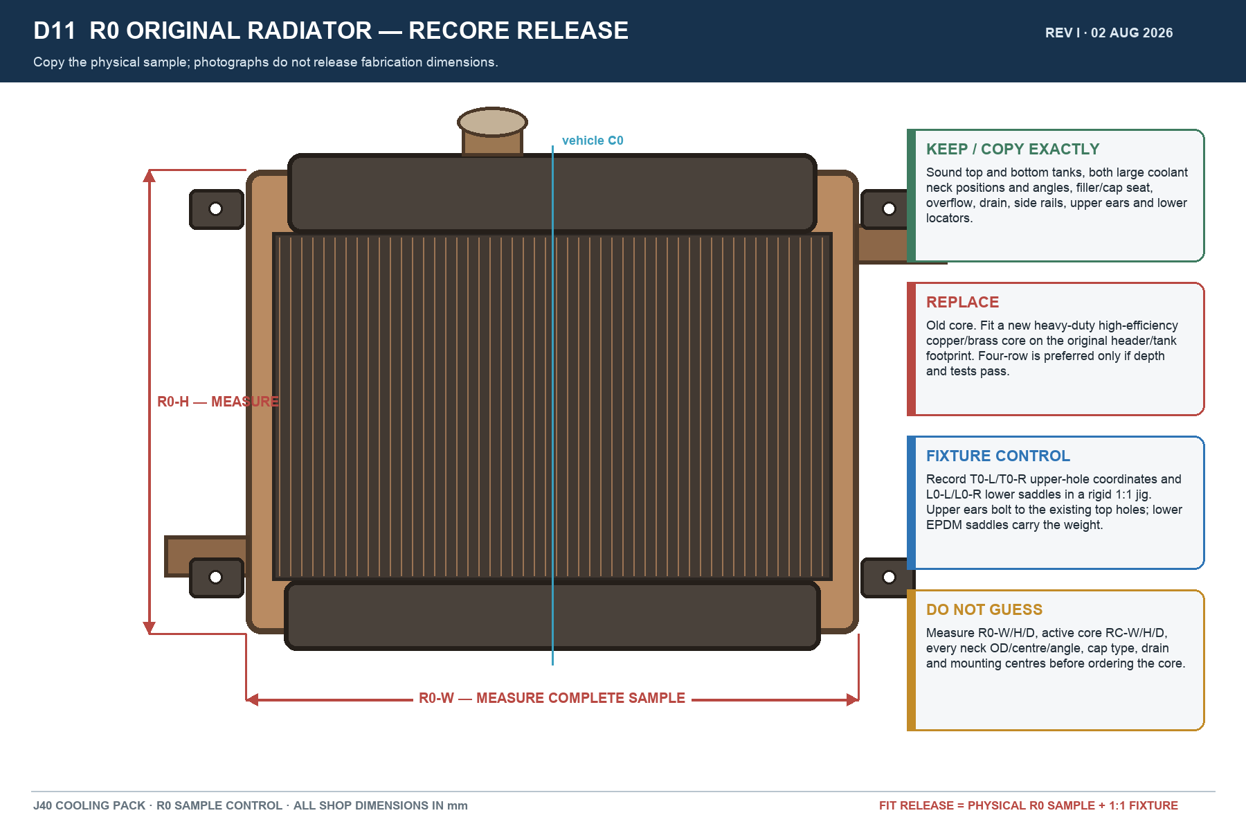
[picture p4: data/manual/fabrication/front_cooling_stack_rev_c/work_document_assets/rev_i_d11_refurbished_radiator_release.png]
R0 measurement and recore release


## 4. Measurement and fit-release sheet

All `MEASURE` fields are filled from the physical vehicle or R0 before the core or brackets are ordered.

| Code | What to record | Release rule / workshop value |
| --- | --- | --- |
| `R0-W` | Maximum complete radiator width, including tanks, seams, side rails and ears | **MEASURE R0:** ______ mm |
| `R0-H` | Maximum height, including filler/cap, necks, drain and locators | **MEASURE R0:** ______ mm |
| `R0-D` | Maximum depth, including seams, neck beads and anything projecting fore/aft | **MEASURE R0:** ______ mm |
| `RC-W/H/D` | Existing active-core width, height and depth | **MEASURE:** ______ × ______ × ______ mm; new core matches header/tank footprint |
| `T0-L / T0-R` | Left/right upper chassis-hole 3D coordinates and centre-to-centre | Copy in a rigid 1:1 fixture; both radiator ears bolt through these existing holes |
| `L0-L / L0-R` | Lower saddle/tab coordinates and span | Copy in the same fixture; lower EPDM saddles carry the radiator weight |
| `N1 / N2` | Each large coolant-neck OD, centre and angle | Copy R0 exactly; record OD ______ / ______ mm |
| `FILL / OV / DR` | Filler neck/cap seat, overflow and drain location/type | Copy R0 exactly |
| `W0-T/M/B` | Clear chassis opening at top, middle and bottom | ______ / ______ / ______ mm; every component stays inside the smallest value |
| `P0` | Available grille-to-engine/fan depth at the tightest point | ______ mm; prove the whole pack before steel cutting |
| `F1` | Two front fan hub centres | `C0 − 133 mm` and `C0 + 133 mm`; exactly 266 mm centre-to-centre |
| `F2` | Rear radiator-to-mechanical-blade static clearance | ≥20 mm; 25–30 mm preferred |
| `F3` | Rear blade radial clearance to shroud | ≥15 mm throughout the sweep |
| `F4` | Fan/belt/engine movement clearance | No contact during engine rock, belt change, hose movement or complete fan sweep |

Fabricator tolerances:

- electric-fan group midpoint to vehicle centreline: ±2 mm;
- left/right electric-fan hub height difference: ≤2 mm;
- hard clearance between metal parts: ≥5 mm;
- top ears must align without pulling or twisting the radiator;
- no component, tab, plug, wire bend, fuse box or relay box may extend beyond `W0`.

## 5. Mounting to the existing chassis

- Use the two existing upright radiator side rails.
- The upper R0 radiator ears must visibly bolt to the existing holes in the inward top returns. Use M8 hardware, sleeves and rubber isolation.
- Lower EPDM saddles carry the radiator weight. Upper bolts locate and retain; they must not crush or twist a tank.
- Make the core stack removable without cutting the welded chassis posts.
- Do not add an outside side tower or widen the front pack to carry electrical parts.
- Put relay and covered MIDI-fuse boxes on independent high/rear brackets with rain hoods, within `W0` and away from heat, water traps, necks, hoses and service paths.
- The stone guard remains independently removable, 10–15 mm ahead of the front fan/shroud face. It must not rub either fan.

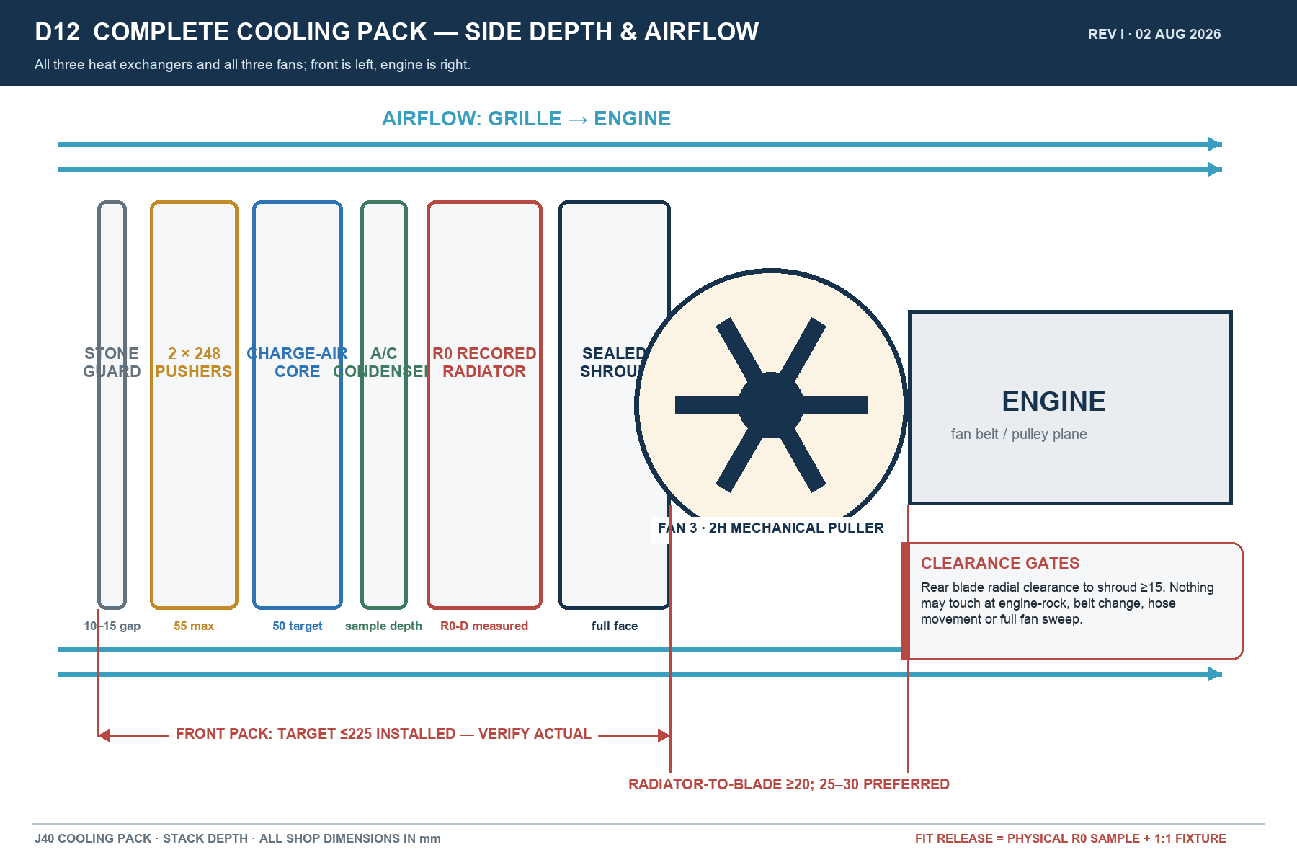
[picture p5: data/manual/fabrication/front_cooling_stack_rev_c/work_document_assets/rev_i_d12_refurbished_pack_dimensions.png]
Side depth and airflow drawing


## 6. Fan layout and control

### Mechanical layout

- Two matched nominal 248 mm Toyota/Denso front pushers.
- Minimum clear ring around each nominal blade: 258 mm.
- Fan hubs at `C0 − 133 mm` and `C0 + 133 mm`, exactly 266 mm apart.
- Both hubs at the same height within 2 mm.
- Use the complete donor frame, tabs, plugs, guards and wire-bend envelope for final checking—not blade diameter alone.
- Front fans push grille-to-engine.
- Rear mechanical fan sits behind the R0 radiator and pulls in the same grille-to-engine direction through the entire stack.

### Electrical roles

| Fan | Normal lead trigger | High-load / failsafe behaviour |
| --- | --- | --- |
| Fan 1 — radiator/A/C pusher | A/C demand or coolant-temperature lead | Both electric fans run on high coolant, high IAT, high A/C pressure, high load, sensor fault or manual override |
| Fan 2 — turbo/charge-air-assist pusher | Intake-air temperature or boost lead | Same shared-stack high/failsafe command as Fan 1 |
| Fan 3 — 2H mechanical puller | Engine-driven | Remains physically behind the radiator and draws air toward the engine |

Use one relay and one closed MIDI-fuse branch per electric fan. Size cable, fuse and relay from the measured installed current with allowance for motor starting current. Provide a single manual override that commands both front fans on.

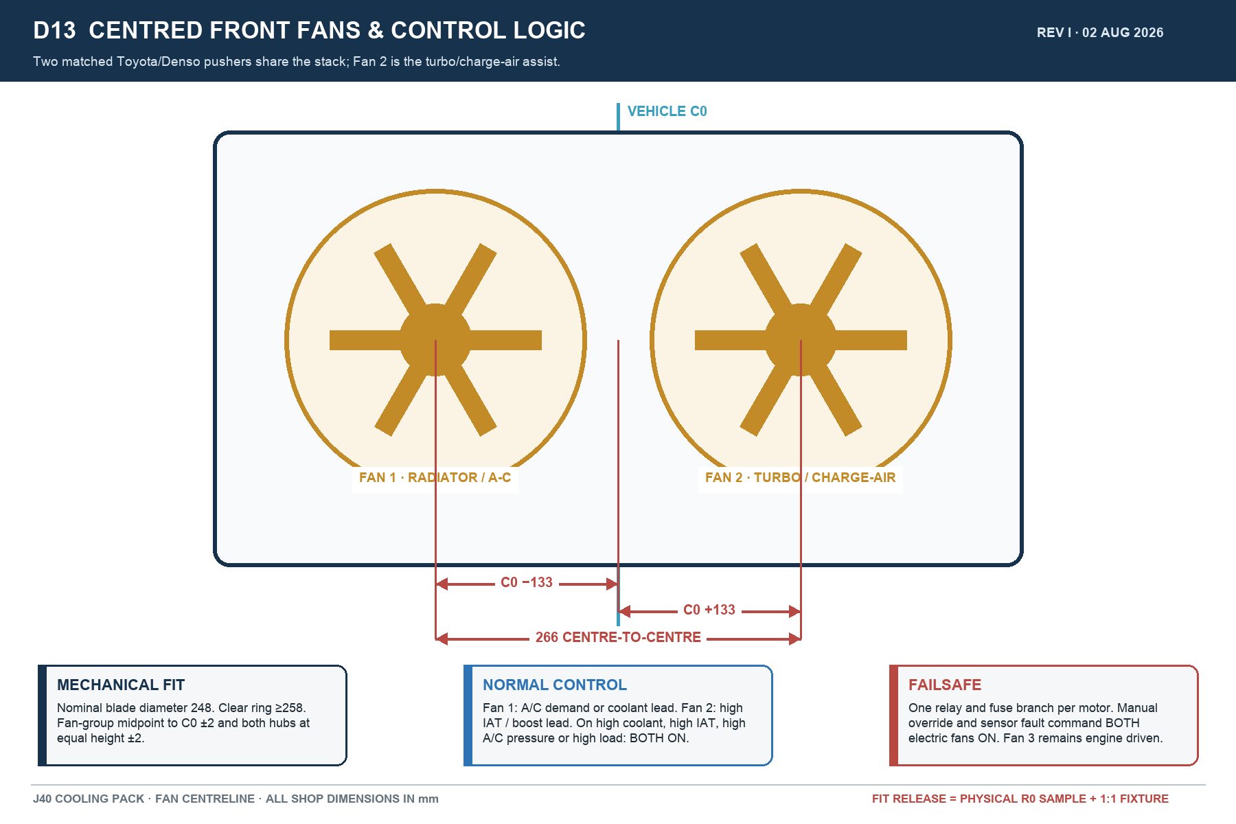
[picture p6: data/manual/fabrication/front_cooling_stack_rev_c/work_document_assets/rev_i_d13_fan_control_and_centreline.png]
Centred front fans and controls


## 7. Heat-exchanger requirements

### Recored R0 engine radiator

- Minimum heat rejection: 115 kW continuous at 50 °C ambient.
- Short-duration heat rejection: 130 kW for 10 minutes at 50 °C ambient.
- Construction: new heavy-duty high-efficiency copper/brass core fitted to the R0 tank/header footprint.
- Exactly two large coolant necks, plus filler/cap, overflow and drain, all copied from R0.
- Full-face rear shroud with sealed edges so the mechanical fan draws through the core rather than around it.

### Charge-air cooler

- Provisional target active core: 500 mm wide × 180 mm high × 50 mm deep, but only after `W0` and `P0` are measured.
- Exactly two 57 mm beaded charge-air ports.
- Minimum duty: 15 kW.
- Complete charge-air route pressure drop: ≤10 kPa at design flow.
- Post-cooler intake-air-temperature release: ≤80 °C at the agreed full-load 50 °C test.

### A/C condenser

- First identify and bench-measure the existing thin aluminium unit.
- Reuse only after pressure testing, flushing, fin condition check, refrigerant fitting check and physical mock-up.
- If it fails, use a physically checked common 14 × 22 inch R134a parallel-flow condenser or equivalent that remains inside `W0`.
- Its small connections are refrigerant fittings. They are not engine-coolant or turbo-charge pipes.

## 8. Depth allowance

The old provisional front-stack calculation was:

| Layer | Provisional depth |
| --- | ---: |
| Two front-fan frames | ≤55 mm |
| Fan-to-charge-core working gap | 5 mm |
| Charge-air cooler | 50 mm target |
| Charge-core to condenser gap | 10 mm |
| A/C condenser | Existing sample to be measured; 21 mm planning allowance only |
| Condenser-to-radiator gap | 10 mm |
| R0 radiator | `R0-D`; must be measured |

The **preferred installed front-pack envelope is ≤225 mm**, but `P0` and actual donor assemblies control. Do not add these provisional values and call the result released until R0, the condenser and the donor fan frames have been measured.

## 9. Standard Toyota / commonly available donor parts

These are search references, not permission to buy unseen parts. Bring samples or templates and measure before paying.

| Item | Preferred donor / reference | Acceptance rule |
| --- | --- | --- |
| Front fan assemblies ×2 | Prado 120 / Lexus GX470 Toyota/Denso 248 mm; `88590-60040`, `88590-60050`, `88590-60051`, `88590-60060` search references | Matching pair, complete frames, plugs and pigtails; verify direction and outside envelope |
| Fan motor | Toyota/Denso `88550-12160` search reference | Two matching working motors with correct connector and pusher rotation |
| Fan blade | Toyota `88453-60010` search reference | Confirm nominal 248 mm and correct rotation |
| Rear mechanical blade | Toyota `16361-68030` / `16361-68031` candidates | Use only after hub, fan sweep, blade count and engine clearance check |
| Rear shroud | Toyota `16711-47040` candidate | Use only if it seals the R0 active face and passes all clearances; otherwise fabricate a full-face shroud |
| A/C condenser | Existing sample after test, or common 14 × 22 inch parallel-flow | Measure fittings, receiver/drier, frame and `W0` before purchase |
| Receiver/drier | Toyota `88471-34010` candidate or common #6 | Refrigerant and port compatibility must be checked |
| Relays | Toyota `90987-02027` or sealed ISO 40 A | One per fan; final rating from measured current |
| Fuses | Closed dual MIDI box with cover | One protected branch per fan; no exposed fuses |

The design source is the original R0 radiator. A Toyota radiator part number such as `16400-68030` may be used only as a comparison/search reference; it does not override R0 fit.

## 10. 50 °C validation

The radiator and turbo are not released by appearance alone. Test the completed vehicle with recorded instruments.

1. Pressure and flow test the recored radiator before installation.
2. Measure installed electric-fan airflow. Aggregate target: ≥3,000 m³/h; 3,300 m³/h preferred.
3. Run hot-idle soak with A/C on.
4. Run repeated low-speed loaded pulls and a sustained loaded road test.
5. Record ambient, coolant-in, coolant-out, pre-cooler IAT, post-cooler IAT, fan states, system voltage and each fan current.
6. Confirm no boiling, coolant loss, hose collapse, fan/shroud contact, belt interference, electrical overheating or progressive temperature rise.
7. Confirm post-cooler IAT ≤80 °C and the agreed coolant-temperature limit at the full-load test condition.
8. Repeat inspection after the first complete heat cycle and again after 100 km.

If a true 50 °C day is unavailable, use an agreed instrumented thermal-load simulation and repeat the hottest available road test. Mark the release sheet with the actual test ambient; do not label it “50 °C tested” unless it was.

## 11. Fabricator sign-off

| Check | Requirement | Result / initials / date |
| --- | --- | --- |
| R0 measured before dismantling | All `R0`, `RC`, `T0`, `L0`, `N1`, `N2`, `W0` and `P0` fields complete | |
| Core and tanks | New core; tanks, rails and necks sound or exact-copy replacements | |
| Top-hole mounting | Both ears bolt through the existing upper holes without strain | |
| Lower mounting | Both EPDM saddles carry the weight and cannot walk out | |
| Electric-fan centring | `C0 ±133`, exactly 266 mm centre-to-centre, midpoint/height within ±2 mm | |
| Rear fan clearances | ≥20 mm axial, 25–30 preferred; ≥15 mm radial | |
| Width and depth | Everything inside `W0`; preferred front pack ≤225 mm; no electrical side growth | |
| Pressure / flow / wiring | Leak-free, flow pass and voltage/current/fuse/relay records complete | |
| 50 °C thermal release | Recorded pass at the stated test condition | |

## 12. Visual references

The photoreal views are for relationship, appearance and workshop communication. They do not replace the physical sample or measurement sheet.

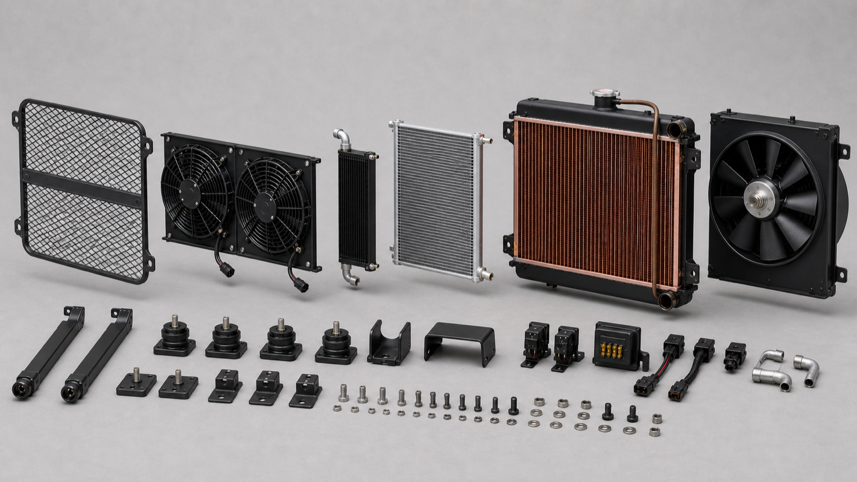
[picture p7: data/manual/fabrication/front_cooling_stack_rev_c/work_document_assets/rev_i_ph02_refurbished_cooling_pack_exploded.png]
Wide exploded component view


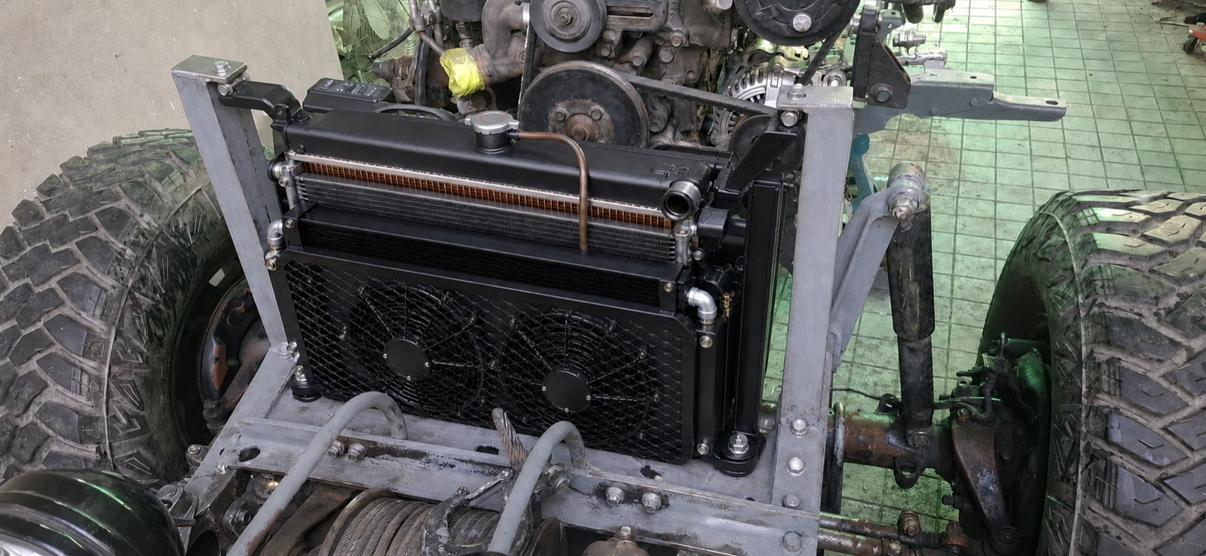
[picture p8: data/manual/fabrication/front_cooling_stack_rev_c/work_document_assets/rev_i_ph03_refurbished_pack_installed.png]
Opaque cooling pack installed on the current chassis


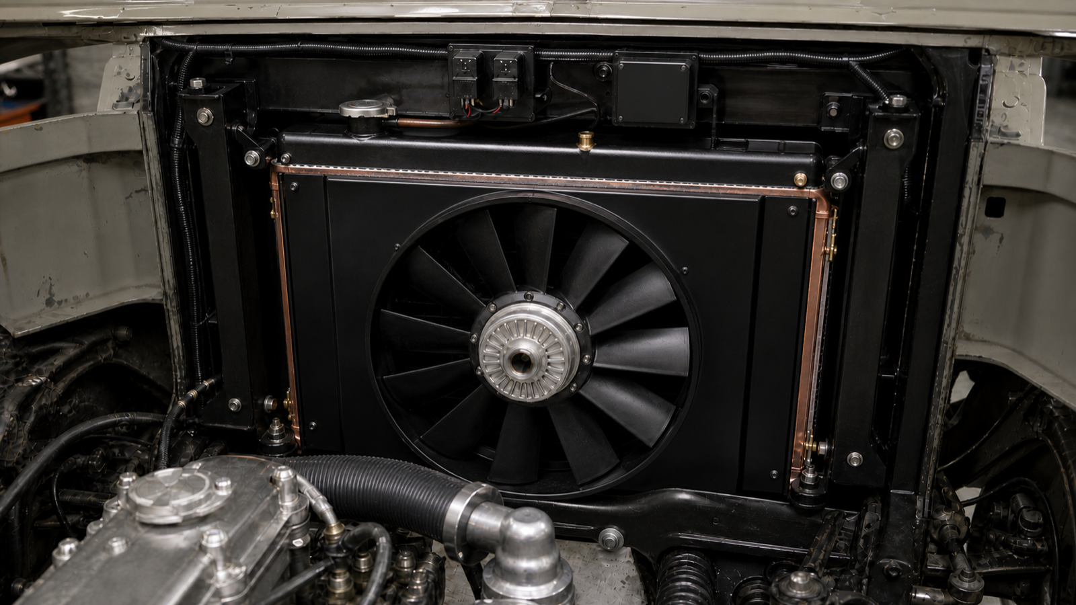
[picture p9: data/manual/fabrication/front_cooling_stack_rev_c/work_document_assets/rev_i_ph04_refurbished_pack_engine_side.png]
Engine-side view showing the rear shroud and mechanical fan


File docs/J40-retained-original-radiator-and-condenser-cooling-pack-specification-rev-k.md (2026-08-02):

# J40 retained original radiator and full-face condenser cooling pack — Rev K

**Issue:** 2 August 2026<br>
**Vehicle/duty:** Toyota J40, Toyota 2H turbo plan, 150 bhp maximum, 50 °C ambient acceptance<br>
**Status:** packaging concept and measurement-controlled shop plan; not yet a fit or thermal release<br>
**Supersedes:** Rev J, whose narrow side-by-side condenser was not the retained project part

## 1. Start here — what the shop is actually building

Use the two real retained heat exchangers shown in the project photographs:

1. **R0 — the original wide copper/brass engine radiator.** This remains the only engine-coolant radiator.
2. **C0 — the original near-full-face A/C condenser, including its existing pipes, receiver/drier and mounting tabs.** Keep it full size if it passes pressure, flush, fin and fit checks.

Add only one new heat exchanger:

3. **K0 — one shallow turbo charge-air cooler (CAC/intercooler).** It is not another water radiator.

There are exactly three installed fans:

- two matching Toyota/Denso-style electric **pushers** at the front, level and horizontally centred as one group on the vehicle centreline; and
- the retained large 2H mechanical **puller** behind R0, moving air toward the engine.

The corrected front-to-rear arrangement is:

**stone guard → two matching centred front fans → shallow low-centred K0 → retained full-face C0 → retained full-face R0 → sealed rear shroud → retained large mechanical fan → engine**

K0 overlaps only the lower central part of C0. The upper C0/R0 face remains a two-core path. This is the smallest simple arrangement that keeps both real retained parts and avoids a side tower. It is a **provisional packaging position** until the complete depth, bumper/grille opening, latch, pipes and service access are measured on the vehicle.

> *Karigar ke liye: purana bara copper/brass radiator R0 aur purana poora A/C condenser C0 dono istemal hon ge. C0 ko aadha ya chhota na banao. Sirf aik naya turbo intercooler K0 neeche, gaari ki centre line par lagay ga. Aagay do aik-jaisay electric pankhay bilkul beech mein; peechay purana bara mechanical pankha engine ki taraf hawa kheenchay ga. Pehle asal parts aur gaari par poora mock-up aur naap; phir welding ya core order.*

## 2. What changed from Rev J

Rev J illustrated an invented narrow condenser beside the CAC. The retained condenser photograph proves that this is wrong: C0 is a broad, near-full-face unit with its own side pipework, receiver/drier and tabs. Rev K therefore:

- preserves the actual C0 shape and fittings;
- preserves the actual R0 tanks, necks, filler, rails, ears and lower locator geometry;
- places C0 in its normal full-face layer directly in front of R0;
- makes K0 the only additional core;
- uses a compact low-front K0 position rather than adding width at either side; and
- keeps all renders subordinate to the physical measurement and test gates below.

Do not fabricate, purchase or quote from any Rev J side-by-side-core image.

## 3. Component identity and action

| ID | Actual item | Action | Release evidence |
| --- | --- | --- | --- |
| R0 | Removed original copper/brass radiator | Clean, inspect, pressure-test and flow-test. Rod/flush or recore only if inspection/test earns it. Preserve sound tanks, filler/cap, overflow, necks, rails, ears and lower locators. | Dimension sheet, neck map, pressure/flow report, installed mount mock-up and 50 °C duty result. |
| C0 | Removed original broad A/C condenser with pipes/drier/tabs | Clean carefully, straighten fins, identify circuit, flush and pressure-test. Reuse complete if sound. The archive supports an approximately 480 × 460 mm finned face, but not the complete assembly envelope. | Complete outside envelope, active face, depth, pipe/port/service envelope, tab coordinates, pressure/flush report. |
| K0 | One new CAC/intercooler | Buy only after the lower-front envelope and pipe route pass the 1:1 mock-up. Use one shallow wide core with tanks and ports inside the vehicle silhouette. | Bought-part drawing and physical sample, pressure test, route fit, IAT and pressure-drop test. |
| F1/F2 | Two matching front electric pusher modules | Prefer a matching Toyota/Denso donor pair. Reuse the existing electric fan only if a true mate is found and both pass the same tests. | Outside envelope, blade sweep, tabs, plug, pusher rotation, start/run current, installed airflow. |
| FM | Retained large 2H mechanical fan and shroud | Inspect/recondition; repair or adapt only enough to seal the R0 active face. | Blade/hub condition, runout, insertion, engine-rock, belt/tool and radial/axial clearances. |
| G0 | Existing removable stone guard | Straighten/repair and keep independently removable. | Open area, attachment points and clearance to rotating parts/cores. |
| E0 | Existing covered relay and MIDI/fuse carrier arrangement | Reuse its aligned inboard position; close every fuse/live stud under a cover. | Closed-lid service sweep, cable bends, drip control, independent support and removal path. |

## 4. Dimensional transfer sheet — complete before buying K0 or cutting steel

All values are in millimetres and are measured from the physical vehicle/parts, not the AI images.

| Datum | Record this measurement | Release rule |
| --- | --- | --- |
| `W0 × H0` | Clear opening inside the finished left/right and upper/lower structure, with grille, bumper and bonnet latch represented | Every core, tank, fan frame, plug, pipe bend and tool sweep remains inside this envelope. |
| `P0-upper` | Grille/guard to rear-fan/shroud clearance through the upper opening | Must accept guard + fan carrier + C0 + gaps + R0 + shroud without contact. |
| `P0-lower` | Same depth through the proposed K0 overlap zone | Must additionally accept the complete K0 tanks/ports and charge-pipe bends. |
| `WR × HR × DR` | Complete R0 outside envelope; also record active face and every neck/ear/locator | Physical R0 controls. No nominal catalogue radiator can override it. |
| `WC × HC × DC` | Complete C0 envelope including drier, pipes, fittings, tabs and service tools. Photo-backed finned face is approximately 480 wide × 460 high; re-measure it. | C0 remains full face; no crop, half-width replacement or relocated drier is authorised by this revision. |
| `WK × HK × DK` | Complete selected K0, including tanks, bosses, brackets and coupler beads | Must fit the released low-centred box and charge route without side extension. |
| `F × HF × DF` | Complete outside envelope of each matching fan module, including frame, guard, motor, plug and tabs | F1 and F2 must be physically matching and must fit the centring formula below. |
| `B0` | Centre-to-centre and X/Y/Z of the two existing horizontal top-return holes | Transfer using one rigid two-hole template. Drill removable radiator ears only. |
| `S0` | Lower saddle centre-to-centre, cup size, locator/pin size and installed rubber height | Both physical R0 lower locators must sit fully in the rubber saddles; no tank, seam or fin may carry load. |
| `L0` | Clear span and end-attachment geometry for the lower load crossmember between the two structural uprights | Crossmember and both end connections must provide a continuous load path into both uprights without using C0, K0 or a fan carrier. |
| `MR` | Actual R0 mass completely filled with coolant and capped | Record before support release; use it for the cradle proof load and fastener/section check. |
| `Rfan` | Rear mechanical fan sweep plus engine movement | No shroud/core/hose contact at static, engine-rock or belt-service conditions. |

### K0 starting target — not a released purchase dimension

Use **approximately 450–500 mm core width × 150–180 mm core height × no more than about 65 mm core depth** only as a first mock-up box. The complete tanks, ports, couplers and brackets will be larger. Change the target to suit measured `W0/H0/P0-lower`; do not force the vehicle or retained C0 around a catalogue intercooler.

### Required depth calculations

Record actual complete-part depths and gaps on the 1:1 fixture:

- upper zone: `P-required-upper = guard + fan carrier + clearance + C0 + 10–15 gap + R0 + rear shroud/fan clearance`;
- lower K0-overlap zone: `P-required-lower = P-required-upper + complete K0 depth + its two anti-contact/service gaps`.

PASS only when both values are less than their measured available depths with bonnet/latch, bumper, grille, pipes, hoses, wiring, service tools and engine movement represented. Do not add the nominal figures on paper and declare fit.

## 5. Front-fan position — visibly central and symmetric

Put F1 and F2 side-by-side at the same height on one removable carrier. Let:

- `Wc` = usable fan-carrier width;
- `F` = outside width of one complete matching module;
- `g` = clear gap between complete modules; use 10–15 mm preferred; and
- `M` = equal left/right outer margin.

Use:

`M = (Wc − 2F − g) / 2`

Release only if:

- `M > 0`;
- left and right margins match within 2 mm;
- the fan-pair midpoint is on vehicle centreline within 2 mm;
- fan hubs are level within 2 mm;
- both units push air from grille to engine;
- the complete pair delivers at least **3,000 m³/h installed at 13.5 V**, with **3,300 m³/h or more preferred**, through the finished guard/cores; and
- plug, cable, blade, guard, tab and removal clearances are proven.

Free-air catalogue CFM is not an installed-airflow test.

## 6. Mounting — a continuous lower load cradle plus both intended top holes

R0 is the largest and heaviest core when filled. It must not appear to float between the uprights and it must not hang from C0, K0, the stone guard or either fan carrier. Its primary load path is:

**R0 lower locators → two Toyota-pattern rubber saddles → full-width lower crossmember → gusseted end connections → both structural side uprights → chassis/front support.**

For a measured clear crossmember span no greater than 700 mm and a completely filled R0 mass no greater than 35 kg, start the fixture with one straight **40 × 40 × 3 mm mild-steel SHS** lower crossmember. Provide a flat saddle seat above it at each measured `S0` location and a drain/open path below. Use two 4 mm triangular gussets at each crossmember/upright junction, approximately 50 mm legs, or an equivalently stiff removable end-plate connection. This is a fabrication starting minimum, not permission to cut: if the actual span/mass exceeds either limit, or the attachment is offset/twisted, recalculate and release the section and connections before manufacture.

Each rubber saddle must fully capture its R0 lower pin/rail while leaving the tank, soldered seam and fins clear of steel. The two saddles must share the load without twisting R0; shim only beneath the removable saddle seat, never by forcing the radiator.

R0 must also visibly and physically attach to both existing upper horizontal return plates. These upper connections resist fore/aft and sideways movement; they do not carry the filled radiator's vertical weight.

At each side:

1. position the short removable black radiator ear directly below the existing hole in the inward-facing grey horizontal top plate;
2. place a large washer and vertical sleeved bolt above that exact hole; select bolt diameter only after measuring the hole and complete bush stack;
3. pass the bolt down through the plate, a sleeved EPDM isolator and the radiator ear;
4. retain it with washer and locking nut below, without crushing the rubber or pulling the radiator sideways; and
5. support R0's weight on two lower rubber saddles.

Both top holes must be occupied. Do not substitute a side-face bolt, new chassis hole, slot, reaming, forced alignment or a visual air gap between the return/isolator/ear stack. C0, K0, fans and electrical boxes each use independent removable brackets; no heat exchanger carries another component.

Before paint, weigh R0 filled and capped, then proof-load the empty cradle vertically to **2 × `MR`** for 10 minutes using a distributed dummy load at the two saddle centres. PASS requires no permanent set, cracked weld, loosened fastener, saddle displacement or upright distortion. Then install R0 and perform a fore/aft/side restraint shake check without metal-to-tank contact.

## 7. Air sealing and serviceability

- Seal fan-carrier edges so air cannot bypass the C0/R0 active face.
- Use a shallow removable lower K0 cradle with rubber isolation and a local duct/seal; do not cable-tie through fins.
- Keep at least 10 mm anti-contact spacing between separate cores unless the 1:1 fixture proves a larger service gap is required.
- C0 and R0 remain separately removable without cutting pipes, brackets or the chassis.
- K0 and its charge pipes remain removable without discharging the A/C circuit.
- Keep radiator cap, drain, hoses, A/C fittings/drier, fan plugs, belts and covered electrical lids accessible.
- Keep the covered relay/MIDI carrier inside the existing front-view silhouette, preferably on the structural carrier above or inboard of the core edge; never add a side tower.

## 8. Electrical control

Each electric fan has its own correctly sized relay, covered MIDI/fuse branch, cable, connector and earth based on measured start/run current and voltage drop.

Normal staged control may use A/C pressure/demand, coolant temperature, boost/high IAT and manual emergency override. High coolant temperature, high IAT, high A/C pressure, high load or sensor/control fault commands both front fans. The large rear mechanical fan remains engine-driven and always pulls toward the engine.

## 9. 50 °C / turbo release — performance must be demonstrated

The layout is intended for 50 °C ambient and the 150 bhp turbo plan, but no image can prove it is comfortable at that duty. Release requires:

- R0 heat rejection target: at least **115 kW continuous** and **130 kW for 10 minutes** at the defined acceptance duty;
- post-CAC IAT no higher than **80 °C** at the agreed boost/load point;
- complete charge-route pressure drop no higher than **10 kPa** at that point;
- no progressive coolant, IAT or A/C-pressure rise at hot idle with A/C operating;
- no boost/load derate caused by cooling inside the accepted 150 bhp envelope; and
- safe currents, voltage drop, cable/fuse/relay temperature, vibration and clearances.

Instrument ambient, coolant inlet/outlet, pre/post-CAC IAT, boost, EGT, A/C high-side pressure, fan commands, system voltage and each fan current. Use a controlled 50 °C cell or documented equivalent heat-soak/load simulation followed by the hottest available road/load test.

If the lower triple-overlap zone causes progressive coolant temperature, excessive A/C head pressure or excessive IAT, **stop**. Do not shrink C0, remove A/C protection or increase boost. First improve sealing/ducting and confirm fan/radiator condition; if it still fails, relocate K0 to an isolated-airflow position or change to a separately engineered water-to-air charge-cooling system under a new revision.

## 10. Fabricator sequence

1. Put actual R0, actual C0, guard, fan/shroud and vehicle in the shop together.
2. Record every row in the dimensional transfer sheet and make rigid `B0` top-hole and `S0` lower-saddle templates.
3. Clean/test R0 and C0; stop if either retained part fails.
4. Build a rigid full-size dummy for the two matching fan modules and proposed K0 complete envelope.
5. Assemble an opaque 1:1 front-to-rear fixture with bumper, grille, latch, pipes, hoses, wiring, covers and service tools represented.
6. Prove the continuous lower-crossmember load path, both saddle centres, both intended top holes, rear fan sweep and every removal path; complete the `2 × MR` cradle proof load.
7. Only then buy K0/fan modules and make removable carriers, ears, seals and covered electrical brackets.
8. Pressure/flow/electrical test, install-airflow test, then instrument the 50 °C duty.
9. Record evidence and owner sign-off before paint/final finish.
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

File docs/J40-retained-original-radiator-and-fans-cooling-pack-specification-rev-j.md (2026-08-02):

# J40 retained-original cooling pack — Rev J

**Issue:** 2 August 2026<br>
**Vehicle/duty:** Toyota J40, Toyota 2H turbo plan, 150 bhp maximum, 50 °C ambient acceptance<br>
**Shop rule:** build from the physical vehicle and retained parts. Dimensions marked `MEASURE` are completed on the 1:1 fixture before steel or cores are ordered. AI images are explanatory only.

## 1. The design in one minute

Retain and refurbish the actual wide copper/brass engine radiator **R0**, its large rear 2H mechanical fan/shroud, removable stone guard, existing front electric fan, existing A/C condenser if serviceable, and covered relay/MIDI-fuse arrangement. Install two matching front pushers, add only one charge-air cooler (CAC), and make only the smallest removable carriers/seals needed to assemble the pack.

There are exactly **three installed fans**:

1. two **matching, equal-size front electric pushers**, horizontally symmetric and centred as one group on vehicle centreline `C0`; and
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

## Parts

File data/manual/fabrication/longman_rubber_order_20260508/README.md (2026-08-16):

# Longman Rubber Order 2026-05-08

> Historical package — do not send to the supplier. It was superseded on
> 2026-07-26 by `../rubber_manufacturer_order_20260726/`, which contains only
> the three approved rubber items and excludes hoses and bump stops.

This folder is the supplier-facing fabrication handoff for the current Longman chassis/body rubber order.

Order it as three supplier-facing things:

1. Simple `80 x 80` body pads: one active `80 x 80 x 24` size, x30, with extras for two-pad stacks where dry-fit proves them. The smaller `22 mm` body-rubber line is removed.
2. Front support / body-support rubbers: `FS-OVAL` x2 plus `2 m` of `38 x 8` strip stock, with `FS-STRIP-L/R` cut as two `420 mm` strips from that stock after dry-fit.
3. Bump stops: `BUMP-60010-LONG` x3 and `BUMP-60020-SHORT` x1.

The part IDs remain the drawing and first-article controls inside those three order groups.

Use it with:

- `docs/longman-rubber-order-spec-20260508.md`
- `data/manual/longman_rubber_order_specs.csv`
- `docs/chassis-rubbers-workstream.md`
- `data/manual/fabrication/rubber_recreation_rev_a/models_3d/`

## 3D Fabrication Assets

- `longman_rubber_order_20260508_3d_visualisation.html` - interactive browser visual for the current order bundle.
- `longman_rubber_order_20260508_3d_visualisation.svg` - static fallback visual.
- `../rubber_recreation_rev_a/models_3d/j40_rubber_models_master.scad` - OpenSCAD master that includes all rubber models.
- `../rubber_recreation_rev_a/models_3d/model_manifest.csv` - part-by-part 3D model index and release status.
- `../rubber_recreation_rev_a/models_3d/old_rubber_checks.md` - old-part checks needed before closing uncertain features.
- `../rubber_recreation_rev_a/bm_iso_lg_square_pad_rev_a.dxf` / `.svg` - single active `80 x 80 x 24` body-pad 2D control; the smaller BM-ISO-SM / 22 mm line is removed from this order.
- `../rubber_recreation_rev_a/bump_stop_vehicle_measurement_control.dxf` / `.svg` - bump-stop May 31 front-shape, metal mounting-ear, central fixture/channel, photo-nominal dimension, and vehicle-measurement control.
- `chassis_rubber_current_order_preview_rev_a.svg` - active Longman order preview sheet; current quote/first-article lines only.
- `../rubber_recreation_rev_a/chassis_rubber_location_map_rev_a.svg` - vehicle-location map for the rubber families in this order.
- `../rubber_recreation_rev_a/chassis_rubber_all_drawings_preview_rev_a.svg` - complete SVG preview showing the active and hold/reference chassis-rubber controls together.

The OpenSCAD files are the source 3D controls. The SVG/DXF files are the 2D shop controls. The HTML/SVG bundle visual is for orientation and communication.

## Current Release

The measured old-rubber photos are the quote and first-article basis for the current Longman order. Remaining checks are station fit, dry-stack compression, any proven two-pad body station, final caliper confirmation for `FS-OVAL`, and local strip trim after dry-fit.

- Body pads: 80 L x 80 W x 24 H square pad, x30, 18.0 mm through bore, R1.5 plan corners, top/bottom edge break or chamfer. Same flat square pad can be doubled only where dry-fit proves extra height is needed. Smaller 22 mm body pad is removed from the order.
- `FS-OVAL`: 96 L x 64 W x 15 T capsule, R32 ends, two 12 mm holes, relief/insert details sample-controlled.
- `FS-STRIP-L/R`: cut two 420 L x 38 W x 8 T plain strips from a 2 m order of 38 x 8 strip stock after dry-fit; allow for the landing path not being perfectly straight; no rubber holes by default.
- Bump stops: copy the broad rounded/tapered rubber body on its metal backing/fixture with exposed mounting ears, central fixture/channel interface, and flat strike area. Photo-derived nominal readings are `~70 mm` long-sample height, `~110 mm` metal-fixture length, `~65 mm` rubber span along the mounting-hole axis, and `~90 mm` metal mounting-hole pitch. Treat them as nearest-`5 mm` identification/first-fit values, not production tolerances. Rear/back stops use the same shape made longer; the right-front target remains `60 mm`. Caliper/thread-gauge the hole diameter/thread, transverse width, fixture details, and vehicle contact geometry before production.

Steel sleeves, cup/seat washers, bolts, shims, and retainers are separate hardware controls, not Longman rubber mould geometry.

Vehicle location is controlled by `../rubber_recreation_rev_a/chassis_rubber_location_map_rev_a.svg`: main body pads sit in the tub-to-chassis mount stack, `FS-OVAL` and `FS-STRIP-L/R` sit at the separate front-support/body-support landings, long bump stops cover front-left and both rear axle stations, and the short bump stop is right-front only.

Hold-only items remain separate from the quote-ready rubber: full-width/body liner strips and exhaust hanger cushion production need an actual sample, installed path, or tracing before ordering.

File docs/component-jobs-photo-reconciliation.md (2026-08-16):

# Component Jobs vs Photo Inventory Reconciliation

- Generated: 2026-08-16 20:36:39
- Source component jobs: `data/manual/component_jobs.csv`
- Source photo inventory: `data/manual/photo_inventory.csv`
- Output CSV: `data/manual/component_jobs_photo_reconciliation.csv`

## Status Summary

- `direct_photo_evidence`: 65
- `indirect_photo_evidence_only`: 4
- `no_photo_evidence`: 30

## Per-Component Results

| Component Job | Status | Direct | Indirect | Direct Components | Notes |
| --- | --- | ---: | ---: | --- | --- |
| `cabin_fuse_relay_donor_samples_20260710` | `no_photo_evidence` | 0 | 0 | `-` | No explicit rule configured. |
| `cavity_wax_station_release_20260816` | `no_photo_evidence` | 0 | 0 | `-` | No explicit rule configured. |
| `cooling_pack_hybrid_restoration_decision_20260816` | `no_photo_evidence` | 0 | 0 | `-` | No explicit rule configured. |
| `engine_manifold_and_side_cover_refresh_20260816` | `no_photo_evidence` | 0 | 0 | `-` | No explicit rule configured. |
| `fitted_late_j40_hydraulic_steering_identification_20260802` | `no_photo_evidence` | 0 | 0 | `-` | No explicit rule configured. |
| `front_brake_sumitomo_refresh_decision_20260816` | `no_photo_evidence` | 0 | 0 | `-` | No explicit rule configured. |
| `front_bumper_recreation_welding_20260719` | `no_photo_evidence` | 0 | 0 | `-` | No explicit rule configured. |
| `handbrake_line_measurement_release_20260816` | `no_photo_evidence` | 0 | 0 | `-` | No explicit rule configured. |
| `j60_hydraulic_bench_inspection_rebuild` | `no_photo_evidence` | 0 | 0 | `-` | No explicit rule configured. |
| `j60_hydraulic_complete_set_acquisition` | `no_photo_evidence` | 0 | 0 | `-` | No explicit rule configured. |
| `j60_hydraulic_existing_interface_capture` | `no_photo_evidence` | 0 | 0 | `-` | No explicit rule configured. |
| `j60_hydraulic_measured_install_validation` | `no_photo_evidence` | 0 | 0 | `-` | No explicit rule configured. |
| `j60_hydraulic_steering_route_decision_20260719` | `no_photo_evidence` | 0 | 0 | `-` | No explicit rule configured. |
| `j60_hydraulic_vehicle_trial_fit` | `no_photo_evidence` | 0 | 0 | `-` | No explicit rule configured. |
| `passenger_footwell_floor_section_replacement_20260719` | `no_photo_evidence` | 0 | 0 | `-` | No explicit rule configured. |
| `pipe_support_adapter_prototype_20260816` | `no_photo_evidence` | 0 | 0 | `-` | No explicit rule configured. |
| `rear_brake_pivot_hardware_identity_20260816` | `no_photo_evidence` | 0 | 0 | `-` | No explicit rule configured. |
| `rear_bumper_recreation_welding_20260719` | `no_photo_evidence` | 0 | 0 | `-` | No explicit rule configured. |
| `relay_midi_radiator_carrier_relocation_20260731` | `no_photo_evidence` | 0 | 0 | `-` | No explicit rule configured. |
| `removed_parts_replace_exclude_20260723` | `no_photo_evidence` | 0 | 0 | `-` | No explicit rule configured. |
| `suspension_bump_stop_direct_bolt_20260816` | `no_photo_evidence` | 0 | 0 | `-` | No explicit rule configured. |
| `suspension_bump_stop_rust_treatment_preparation_20260723` | `no_photo_evidence` | 0 | 0 | `-` | No explicit rule configured. |
| `toolbench_market_scout_close_20260816` | `no_photo_evidence` | 0 | 0 | `-` | No explicit rule configured. |
| `turbo_engine_health_release_20260717` | `no_photo_evidence` | 0 | 0 | `-` | No explicit rule configured. |
| `turbo_hot_side_fabrication_20260717` | `no_photo_evidence` | 0 | 0 | `-` | No explicit rule configured. |
| `turbo_instrument_electrical_integration_20260717` | `no_photo_evidence` | 0 | 0 | `-` | No explicit rule configured. |
| `turbo_intake_charge_breather_connections_20260717` | `no_photo_evidence` | 0 | 0 | `-` | No explicit rule configured. |
| `turbo_oil_cooling_connections_20260717` | `no_photo_evidence` | 0 | 0 | `-` | No explicit rule configured. |
| `turbo_staged_validation_20260717` | `no_photo_evidence` | 0 | 0 | `-` | No explicit rule configured. |
| `winch_motor_drive_shaft_connection_20260729` | `no_photo_evidence` | 0 | 0 | `-` | No explicit rule configured. |
| `exhaust_mockup_brackets_before_coating_20260508` | `indirect_photo_evidence_only` | 0 | 37 | `-` | Current photo inventory has no dedicated exhaust mock-up evidence; chassis and engine-bay photos only support routing context. |
| `front_caliper_holder_fit_check_20260712` | `indirect_photo_evidence_only` | 0 | 13 | `-` | Owner reports donor caliper holders/carriers are in hand, but the July 12 picker batch did not include a distinct holder photo. Existing front Sumitomo disc photos are vehicle-side context only; closure needs donor-holder photos and physical fit checks. |
| `suspension_grinder_damage_weld_repair_20260712` | `indirect_photo_evidence_only` | 0 | 40 | `-` | Owner reports an experienced welder will correct the angle-grinder damage on the suspension area. Existing suspension photos are context only; closure needs repair photos, geometry check, primer touch-in, and fitment signoff. |
| `suspension_upgrade_spec_and_kit_lock` | `indirect_photo_evidence_only` | 0 | 40 | `-` | Vehicle-side suspension photos support fitment constraints only; the kit lock still needs part-number, quantity, and arrived-condition photos for the actual suspension kit. |
| `auxiliary_chassis_tabs_and_clip_brackets_20260508` | `direct_photo_evidence` | 15 | 20 | `frame_rail_body_mount_and_hard_line_detail|rear_mid_frame_rail_and_hard_line_detail` | Hard-line and frame-rail photos show existing clip/tab areas; current audit photos are still required before deciding which auxiliary tabs to weld. |
| `back_cabin` | `direct_photo_evidence` | 7 | 15 | `body_shell_with_doors_removed|dashboard_shell_and_cabin|rear_cargo_floor|rear_side_opening` | Rear cabin/body section is directly visible in multiple strip-down shots. |
| `back_doors` | `direct_photo_evidence` | 19 | 2 | `detached_body_panels_and_doors|detached_doors_and_panels` | Detached door panels are direct; interior door card is supporting context. |
| `battery_power_carrier_mount_fabrication_20260508` | `direct_photo_evidence` | 7 | 21 | `battery_side_tray_structure_context|existing_battery_mount_tray_measurements|installed_battery_dimension_reference` | Procurement photos document the MIDI/cutoff hardware separately; May 17 battery and existing tray measurements now provide the real carrier datum, but cardboard/flat-bar mock-up and final pickup release photos are still required before cutting. |
| `battery_tray_holder_bracket_repair_20260508` | `direct_photo_evidence` | 7 | 40 | `battery_side_tray_structure_context|existing_battery_mount_tray_measurements|installed_battery_dimension_reference` | Engine-bay overview photos show the battery-side location; May 17 adds actual installed-battery dimension and existing tray/mount ruler evidence, while underside foot condition and dry-fit pickup templates still need closure. |
| `body_mount_points_and_captive_nuts` | `direct_photo_evidence` | 22 | 58 | `body_mount_and_crossmember_detail|frame_and_mount_points|frame_rail_body_mount_and_crossmember_detail` | Mount pedestal and frame-mount photos support thread/captive-nut condition checks before refit. |
| `body_rubbers` | `direct_photo_evidence` | 7 | 8 | `front_vent_window_assemblies|side_window_glass_and_channels|window_rubber_seals_and_frames` | Detached window assemblies, channels, and rubber surrounds are directly documented; non-window body-mount rubber remains controlled separately. |
| `brake_booster_servo_refurbishment_20260529` | `direct_photo_evidence` | 7 | 0 | `brake_booster_servo_removed_sample` | May 29 removed booster/servo photos record its pre-tidy condition and interfaces. Owner confirmation on July 29 closes the functional concern: the booster is fine and needs cosmetic tidying only. Preserve the shell joint, pushrod/free-play, clevis, boot, check valve, grommet, studs, and master-cylinder interface during cosmetic work; validate the assembled brakes in the wider brake-system closeout. |
| `brake_hydraulic_refresh_and_bias_decision` | `direct_photo_evidence` | 65 | 33 | `brake_booster_servo_removed_sample|frame_floor_underside_and_lines` | Hard-line routing and removed booster/servo photos are direct evidence for the system refresh decision; axle-end hardware views support brake-bias and wear decisions. Owner-confirmed replacement scope still needs sample matching and final bleed/road validation. |
| `brake_system_evidence_pack` | `direct_photo_evidence` | 131 | 2 | `brake_booster_servo_removed_sample|frame_and_mount_points|frame_floor_underside_and_lines|front_sumitomo_disc_caliper_and_rotor_baseline|rear_axle_and_leaf_springs|rear_drum_backing_plate_contact_and_anchor_area|rear_drum_brake_current_parts_inventory_20260705|rear_drum_brake_removed_hardware_layout|rear_drum_hold_down_spring_pin_set_reconditioned_20260712|rear_drum_hub_and_backing_plate_condition_20260716|rear_drum_parking_brake_reconditioned_hardware_20260712|rear_drum_reconditioned_hardware_update_20260716|steering_and_suspension_linkages` | Brake evidence pack combines direct Sumitomo front-disc closeups, rear axle hardware views, underbody hard-line photos, removed booster/servo sample, and July 12 reconditioned rear drum/parking-brake hardware. May 29 owner confirmation treats the brake parts as replacement scope, with old parts retained only as samples. |
| `cabin_engine_firewall_holes_survey_20260517` | `direct_photo_evidence` | 4 | 17 | `cabin_engine_firewall_pass_through_holes` | May 17 selected photos are the active cabin-to-engine firewall hole survey; size, edge condition, grommet availability, and routing assignment must be logged before reusing or closing any opening. |
| `chassis_bracket_analysis_register_20260508` | `direct_photo_evidence` | 55 | 25 | `battery_side_tray_structure_context|frame_rail_body_mount_and_crossmember_detail|frame_rail_body_mount_and_hard_line_detail|front_frame_horns_bumper_and_radiator_support|front_frame_horns_bumper_and_steering_area|front_support_radiator_pickups_context|rear_mid_frame_rail_and_hard_line_detail` | Use the existing body-off chassis photos as baseline evidence, then close this row only after a station-by-station bracket register records function, condition, evidence, and coating impact. |
| `chassis_bracket_design_release_20260508` | `direct_photo_evidence` | 43 | 33 | `battery_side_tray_structure_context|frame_rail_body_mount_and_hard_line_detail|front_frame_horns_bumper_and_radiator_support|front_frame_horns_bumper_and_steering_area|front_support_radiator_pickups_context|rear_mid_frame_rail_and_hard_line_detail` | Location photos support the bracket design baseline, but released sketches/templates with material, hole/stud, bend, datum, and clearance decisions are still required before fabrication. |
| `chassis_bracket_fabrication_install_20260508` | `direct_photo_evidence` | 39 | 25 | `frame_rail_body_mount_and_hard_line_detail|front_frame_horns_bumper_and_radiator_support|front_frame_horns_bumper_and_steering_area|front_radiator_two_side_retention_20260722|front_winch_crossmember_structure_context_20260722|major_round_tube_structural_crossbar_reinstatement_20260722|rear_mid_frame_rail_and_hard_line_detail` | July 22 images show the second radiator arm and reinstated structural crossbar after fabrication. Physical work is reported complete; closure still needs close weld/geometry/clearance evidence, radiator dry fit, and primer/Raptor touch-in. |
| `chassis_bracket_validation_release_20260508` | `direct_photo_evidence` | 51 | 25 | `frame_rail_body_mount_and_crossmember_detail|frame_rail_body_mount_and_hard_line_detail|front_frame_horns_bumper_and_radiator_support|front_frame_horns_bumper_and_steering_area|front_radiator_two_side_retention_20260722|front_winch_crossmember_structure_context_20260722|major_round_tube_structural_crossbar_reinstatement_20260722|rear_mid_frame_rail_and_hard_line_detail` | Baseline and July 22 installed-work photos support the validation checklist. Final release still requires close weld/heat-affected-zone views, geometry and clearance measurements, radiator/isolator dry fit, and coating restoration. |
| `chassis_frame_and_crossmembers` | `direct_photo_evidence` | 111 | 40 | `frame_and_mount_points|frame_floor_underside_and_lines|frame_rail_body_mount_and_crossmember_detail|front_frame_horns_bumper_and_steering_area|front_winch_crossmember_structure_context_20260722|major_round_tube_structural_crossbar_reinstatement_20260722|rear_frame_crossmember_and_mounts|rear_half_chassis_primer_application|rear_mid_frame_rail_and_hard_line_detail` | Body-off underside shots, May 1 post-brushing photos, July 4 rear-half primer photos, and the July 22 reinstated structural-crossbar image provide direct chassis/crossmember evidence. The new weld still needs both-end inspection, geometry/clearance checks, and coating touch-in. |
| `chassis_hard_lines_and_brackets` | `direct_photo_evidence` | 67 | 47 | `frame_floor_underside_and_lines|rear_mid_frame_rail_and_hard_line_detail` | Underbody routing photos and May 1 hard-line/rail shots give direct visibility to line paths/brackets and nearby support hardware. |
| `chassis_missing_welded_bracket_survey_20260508` | `direct_photo_evidence` | 48 | 25 | `frame_rail_body_mount_and_crossmember_detail|frame_rail_body_mount_and_hard_line_detail|front_frame_horns_bumper_and_radiator_support|front_frame_horns_bumper_and_steering_area|rear_mid_frame_rail_and_hard_line_detail` | Existing body-off chassis photos provide the survey baseline, but the task remains open until current close-ups label every missing, wire-tied, or required bracket. |
| `chassis_rear_half_primer_application_20260704` | `direct_photo_evidence` | 6 | 16 | `rear_half_chassis_primer_application` | July 4 picker batch documents partial rear/back-half chassis primer application. Treat as coating evidence for that zone only; topcoat release still needs hole/thread cleanup, inner-face touch-in, stand-contact touch-up, and front/remaining chassis coverage. |
| `chassis_wire_brush_status_20260501` | `direct_photo_evidence` | 42 | 19 | `frame_rail_body_mount_and_crossmember_detail|front_frame_horns_bumper_and_steering_area|rear_axle_spring_hanger_and_crossmember|rear_mid_frame_rail_and_hard_line_detail` | May 1 photos directly document the current post-wire-brushing chassis state and the remaining rust-prep closeout zones. |
| `engine_bay_mounting_scouting_pass_20260508` | `direct_photo_evidence` | 40 | 6 | `battery_side_tray_structure_context|cooling_hoses_fan_belt_and_radiator_support|engine_bay_overview|existing_battery_mount_tray_measurements|front_frame_horns_bumper_and_radiator_support|front_support_radiator_pickups_context|installed_battery_dimension_reference` | Current photos are enough to start the radiator/battery/power-carrier plan; May 17 imports actual battery and tray/mount measurements, while cardboard mock-up, cable sweep, and pickup release checks remain open. |
| `engine_cooling_pipe_fabrication_samples` | `direct_photo_evidence` | 29 | 24 | `cooling_pipe_fabrication_samples` | May 2 selected pipe photos directly document the made-to-order cooling pipe sample set; engine-bay routing photos provide supporting context. |
| `engine_electrical_inputs_reconciliation_20260517` | `direct_photo_evidence` | 10 | 34 | `alternator_charge_regulator_wiring|engine_input_loom_routing_context|engine_loose_connector_unassigned|engine_sender_branch|engine_starter_solenoid_and_ground_inputs|engine_unidentified_two_wire_connector|injection_pump_throttle_linkage_electrical_input` | May 17 selected photos are the active engine electrical input reconciliation set; starter, alternator, sender, injection-pump/throttle-linked, and unknown connector branches must be labelled and electrically proven before final wrap. |
| `engine_powertrain_cleaning_20260501` | `direct_photo_evidence` | 19 | 23 | `engine_powertrain_cleaning_baseline` | May 1 engine, gearbox, transfer, steering, and driveline photos directly document the cleaning baseline before degreasing and leak inspection. |
| `engine_radiator_recore_or_new_20260529` | `direct_photo_evidence` | 18 | 12 | `ac_condenser_sample_measurement|cooling_hoses_fan_belt_and_radiator_support|engine_radiator_condition_closeups|front_support_radiator_pickups_context` | May 29 radiator sample and condition photos add direct removed-radiator width/height/side-bracket, core/fin, lower-mount, and added-leg evidence. Existing cooling and front-support photos provide hose/fan/vehicle-side fitment context; shop release still requires pressure/flow test and final dry-fit clearance proof. |
| `floor_pan` | `direct_photo_evidence` | 49 | 60 | `floor_pan_and_firewall|floor_pan_rust_zones|floor_seam_and_body_mount_rust` | Floor pan rust/condition is directly evidenced with dedicated close-ups; May 17 adds tub floor, seam, and body-mount rust details. |
| `front_brake_disc_baseline` | `direct_photo_evidence` | 13 | 11 | `front_sumitomo_disc_caliper_and_rotor_baseline|steering_and_suspension_linkages` | May 29 closeups directly identify the front disc baseline as visible Sumitomo fixed-caliper hardware with bridge pipe, hose/hard-line routing, dust shield, and rotor; older steering/linkage photos remain supporting context. |
| `front_radiator_bracket_repair_20260508` | `direct_photo_evidence` | 19 | 21 | `cooling_hoses_fan_belt_and_radiator_support|front_frame_horns_bumper_and_radiator_support|front_radiator_two_side_retention_20260722|front_support_radiator_pickups_context` | July 22 front-structure evidence shows the second radiator arm present and reported welded. Fabrication is complete; closure still needs weld/heat-affected-zone closeups, side-to-side geometry, radiator/isolator dry fit, fan/shroud/hose/bonnet clearance, and coating touch-in. |
| `front_radiator_two_side_retention_fabrication_20260508` | `direct_photo_evidence` | 19 | 21 | `cooling_hoses_fan_belt_and_radiator_support|front_frame_horns_bumper_and_radiator_support|front_radiator_two_side_retention_20260722|front_support_radiator_pickups_context` | The July 22 front-structure photo shows both radiator arms and supports the report that the second arm is welded in. Keep installation release open for weld inspection, pickup alignment, rubber isolation, radiator dry fit and fan/shroud/hose clearance. |
| `front_vent_window_assemblies` | `direct_photo_evidence` | 3 | 6 | `front_vent_window_assemblies` | Detached paired vent/quarter window assemblies are directly documented and should close through the windows refurbishment gate. |
| `front_windows` | `direct_photo_evidence` | 2 | 20 | `hood_and_front_windshield_overview` | Front windshield is explicitly captured in dedicated front overview shots; May 17 side-window glass photos support the broader windows workstream. |
| `front_wings` | `direct_photo_evidence` | 6 | 38 | `detached_body_panels_and_doors|detached_doors_and_panels` | Front wings are tracked to paint from the April 23 send-day detached-parts batch; wing-removal photos are supporting context only. |
| `gearbox_oil_service_drain_inspect_refill_20260529` | `direct_photo_evidence` | 22 | 4 | `bellhousing_clutch_linkage_and_gearbox_case|engine_powertrain_cleaning_baseline` | Existing gearbox and powertrain photos establish location and access context. Closeout still needs fill plug, drain plug, oil sample, drain plug debris, oil product, refill, and leak-check photos. |
| `gearbox_top_cover_shift_tower_20260518` | `direct_photo_evidence` | 22 | 4 | `bellhousing_clutch_linkage_and_gearbox_case|engine_powertrain_cleaning_baseline` | Gearbox case, bellhousing, linkage, underside, and May 12 powertrain views support top-cover identification and shift-tower planning; open-top inspection photos are still required before parts release. |
| `hood` | `direct_photo_evidence` | 2 | 16 | `hood_and_front_windshield_overview` | Hood panel/latches are explicitly visible in front overview shots. |
| `interior` | `direct_photo_evidence` | 50 | 4 | `cabin_overview|dashboard_and_cabin_stripdown|dashboard_lower_structure|dashboard_shell_and_cabin|driver_footwell_firewall_and_wiring|floor_pan_and_firewall|rear_cargo_floor` | Interior strip-down and cabin state are well documented. |
| `interior_dash_switch_fitup` | `direct_photo_evidence` | 3 | 1 | `dashboard_switch_and_control_hardware` | April 21 dashboard switch/control hardware photos provide direct evidence for the fit-up row; final closure still needs installed position, mounting, labelling, and functional check photos. |
| `interior_diesel_cutoff_ignition_security` | `direct_photo_evidence` | 4 | 0 | `dashboard_switch_and_control_hardware|hidden_diesel_cutoff_switch_hardware` | April 20 hidden diesel-cutoff hardware and April 21 dashboard switch/control photos provide direct hardware evidence; final closure still needs hidden routing, ignition interlock, access-control, and function-test photos. |
| `issue_body_mount_captive_thread_repair` | `direct_photo_evidence` | 22 | 58 | `body_mount_and_crossmember_detail|frame_and_mount_points|frame_rail_body_mount_and_crossmember_detail` | Body-mount pedestal and mount-point photos cover captive-nut and sleeve/thread repair planning. |
| `issue_brake_fuel_line_clip_corrosion` | `direct_photo_evidence` | 67 | 47 | `frame_floor_underside_and_lines|rear_mid_frame_rail_and_hard_line_detail` | Underbody line-routing photos and May 1 rail/hard-line details are the primary evidence for clip/bracket corrosion and hard-line condition checks. |
| `issue_chassis_ground_points_refresh` | `direct_photo_evidence` | 70 | 24 | `frame_floor_underside_and_lines|frame_rail_body_mount_and_crossmember_detail` | Frame and lower bay views provide context for grounding point cleanup and re-termination planning. |
| `issue_crossmember_end_thinning_check` | `direct_photo_evidence` | 23 | 81 | `body_mount_and_crossmember_detail|frame_rail_body_mount_and_crossmember_detail|rear_frame_crossmember_and_mounts|rear_mid_frame_rail_and_hard_line_detail` | Crossmember and mount-detail photos are used to inspect end-wall thinning and edge corrosion. |
| `issue_front_spring_hanger_crack_check` | `direct_photo_evidence` | 33 | 9 | `rear_axle_and_leaf_springs|rear_axle_spring_hanger_and_crossmember|suspension_or_linkage_mount` | Spring and hanger views provide direct evidence for crack/deformation checks around hanger brackets. |
| `issue_steering_box_mount_crack_check` | `direct_photo_evidence` | 23 | 11 | `front_frame_horns_bumper_and_steering_area|steering_and_suspension_linkages` | Steering linkage and nearby mount photos are the baseline evidence set for steering-box mount crack checks. |
| `major_structural_round_tube_crossbar_reinstatement_20260722` | `direct_photo_evidence` | 1 | 59 | `major_round_tube_structural_crossbar_reinstatement_20260722` | July 22 image directly shows the major round-tube structural crossbar reinstated between the rails. Fabrication is reported complete; both ends, rail condition, geometry, driveline/line clearance and corrosion protection still require closeout evidence. |
| `old_accessory_wiring` | `direct_photo_evidence` | 17 | 4 | `driver_footwell_firewall_and_wiring|driver_footwell_firewall_pass_through|firewall_and_dash_wiring|pedal_box_wiring` | Accessory/electrical removal and rebuild work has strong direct photo coverage. |
| `paint_returned_panels_refinished` | `direct_photo_evidence` | 30 | 4 | `refinished_hinges_brackets_and_trim|refinished_seat_or_mount_bracket|returned_painted_body_trim|returned_painted_brackets_and_trim|returned_painted_front_panel_headlamp_surround|returned_painted_front_wings|returned_painted_inner_panels_or_splash_shields|roof_gutter_and_window_channel|wiper_arm_or_linkage_hardware` | Off-vehicle refinished hardware/panel photos, the May 17 returned roof image, and the May 23 picker batch provide direct evidence of returned painted parts. |
| `paint_sendout_panels_manifest` | `direct_photo_evidence` | 21 | 4 | `detached_body_panels_and_doors|detached_doors_and_panels|rear_hatch_inner_panel|roof_gutter_and_window_channel` | Detached panel/door batches and the April 23 roof image provide direct send-out evidence for painting. |
| `paint_workshop_progress_media` | `direct_photo_evidence` | 5 | 19 | `off_vehicle_workstation_reference_video|panel_detail_and_markings` | In-progress workshop videos and panel-handling shots track painting/bodywork activity between send-out and return; stripdown wing-removal photos are not direct paint evidence. |
| `rear_brake_cable_line_refresh` | `direct_photo_evidence` | 44 | 74 | `rear_axle_and_leaf_springs|rear_drum_backing_plate_contact_and_anchor_area|rear_drum_brake_current_parts_inventory_20260705|rear_drum_brake_removed_hardware_layout|rear_drum_hold_down_spring_pin_set_reconditioned_20260712|rear_drum_hub_and_backing_plate_condition_20260716|rear_drum_parking_brake_reconditioned_hardware_20260712|rear_drum_reconditioned_hardware_update_20260716` | Rear axle/drum photos directly show the parking-brake cable/linkage, axle-end hard-line routing, removed spring/lever hardware, and July 12 reconditioned pieces. Small clevis/equalizer/spring/clip hardware remains controlled separately. |
| `rear_brake_drum_baseline` | `direct_photo_evidence` | 47 | 58 | `rear_axle_and_leaf_springs|rear_brake_shoe_fit_rejection_20260722|rear_drum_backing_plate_contact_and_anchor_area|rear_drum_brake_current_parts_inventory_20260705|rear_drum_brake_removed_hardware_layout|rear_drum_hold_down_hardware_pool_complete_20260722|rear_drum_hold_down_spring_pin_set_reconditioned_20260712|rear_drum_hub_and_backing_plate_condition_20260716|rear_drum_operating_parking_brake_hardware_pool_complete_20260722|rear_drum_parking_brake_reconditioned_hardware_20260712|rear_drum_reconditioned_hardware_update_20260716` | Rear axle/drum images plus the July 22 hold-down and operating-hardware photos document the reported-complete non-friction parts pool. The July 22 fit photo rejects K-2255 as too wide; correct K-2221 shoes, hardware count/condition/layout checks, rusty drum/backing-plate preparation, assembly and functional validation remain open. |
| `rear_differential_axle_inspection_20260517` | `direct_photo_evidence` | 25 | 74 | `rear_axle_and_leaf_springs|rear_differential_carrier_and_axle_housing` | User-supplied May 17 differential carrier/pumpkin close-up triggers a rear differential/axle teardown inspection plan; existing rear axle, brake-line, and spring photos provide supporting route and access context. Closure needs DIFF-CAPTURE-001 with oil/debris, breather, carrier sealing, gear teeth, axle seal/bearing, fill, and leak-check evidence. |
| `rear_fuel_tank` | `direct_photo_evidence` | 4 | 58 | `fuel_filler_side_panel|rear_cargo_floor` | Fuel tank-out context and tank-area access are documented in filler-side and rear-floor images. |
| `rear_parking_brake_attachment_hardware_20260527` | `direct_photo_evidence` | 21 | 29 | `rear_axle_and_leaf_springs|rear_drum_brake_current_parts_inventory_20260705|rear_drum_brake_removed_hardware_layout|rear_drum_hold_down_hardware_pool_complete_20260722|rear_drum_hold_down_spring_pin_set_reconditioned_20260712|rear_drum_operating_parking_brake_hardware_pool_complete_20260722|rear_drum_parking_brake_reconditioned_hardware_20260712|rear_drum_reconditioned_hardware_update_20260716` | July 22 photos support the owner report that the rear-drum hold-down and parking-brake/operating hardware pool is complete. Procurement is provisionally closed; side/location control, counts, wear/retention checks, spring comparison, adjuster/lever movement and full free return still gate installation. |
| `removed_reusable_parts_refresh_repaint_20260723` | `direct_photo_evidence` | 11 | 0 | `front_door_latch_central_locking_sets_20260723|glovebox_lid_refresh_repaint_20260723|oil_filler_breather_tube_identification_20260723|parking_brake_cable_linkage_reconstruction_sample_20260723|pedal_area_dual_plunger_switch_bracket_20260723|single_stamped_latch_adjuster_identification_20260723|suspension_bump_stop_set_20260722|unidentified_lever_pieces_refurbisher_identification_20260723|windscreen_wiper_motor_assessment_20260723` | The revised selector is directly supported by the eleven July 23 part photos plus the separately tracked bump-stop set. Mechanical, electrical and cable items require specialist assessment before cosmetic work; identify-first labels remain mandatory where the function is not proven. |
| `replacement_pipe_ordering_matrix` | `direct_photo_evidence` | 14 | 0 | `bellhousing_clutch_linkage_and_gearbox_case|bilal_ganj_replacement_pipe_hose_set_20260712|cooling_hoses_fan_belt_and_radiator_support|cooling_pipe_fabrication_samples|frame_rail_body_mount_and_hard_line_detail|replacement_pipe_hose_sample_sorting` | Replacement pipe ordering is limited to selected pipe sample photos, close pipe/hose/line location evidence, and the July 12 received pipe/hose/clamp set. Body rubbers and broad chassis/mechanical context are excluded; exact circuit assignment still needs old-route matching. |
| `roof_shell` | `direct_photo_evidence` | 6 | 0 | `roof_gutter_and_window_channel` | Roof channel/rain gutter photos are direct evidence of roof shell condition. |
| `suspension_bump_stop_install_20260712` | `direct_photo_evidence` | 10 | 40 | `suspension_bump_stop_install_set_20260712|suspension_bump_stop_removed_samples|suspension_bump_stop_set_20260722` | July 12 Bilal Ganj photos show the new bump-stop set in hand. Install at the front/rear spring bump-stop brackets only after rust-treating the metal mounting plates and confirming station fit/clearance. |
| `suspension_upgrade_fitment_and_alignment` | `direct_photo_evidence` | 40 | 23 | `rear_axle_and_leaf_springs|rear_axle_spring_hanger_and_crossmember|steering_and_suspension_linkages` | Rear spring/U-bolt and front linkage photos provide direct fitment context; final alignment release still needs installed-kit and ride-height/alignment photos. |
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

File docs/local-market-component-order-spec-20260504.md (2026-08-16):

# Local Market Component Order Spec - 2026-05-04

Purpose: one sendable market pack that lists the actual new parts to quote or buy, with the working dimensions already pulled out. Take old samples and photos where noted; do not let the market turn this back into generic "rubber pipe" or "Land Cruiser part" shopping.

Supersession note 2026-05-12: the hose, fuel/vacuum hose, pipe, hard-line, and brake/clutch hydraulic hose rows are no longer a scout/local-market task. Use [Longman Pipe And Hose Order Spec](longman-pipe-hose-order-spec-20260512.md) for the active supplier request. The sections below remain as archived extracted dimensions and reject rules only.

Scout position: parking-brake cable, rubber/grommet/boot/pad, clamp, clip, fitting, terminal, electrical wire/cable consumables, and other local-only problem parts are new replacement requirements. Old components are used only as samples for length, shape, fittings, routing, and connector identification.

New-only rule: do not buy used/salvage rubbers, hoses, hydraulic assemblies, hard lines, parking-brake cables, electrical wire/cable, terminals, clips, clamps, fittings, grommets, boots, pads, hangers, or similar consumables for final installation.

The dashboard Scout tables now use current-car crops for hose, pipe, brake, fuel, and clutch rows where usable photos exist, plus the user-supplied compact fuse-box photo and catalog references for the brake booster and workshop bench.

## Photo References

| Component family | Photo reference |
| --- | --- |
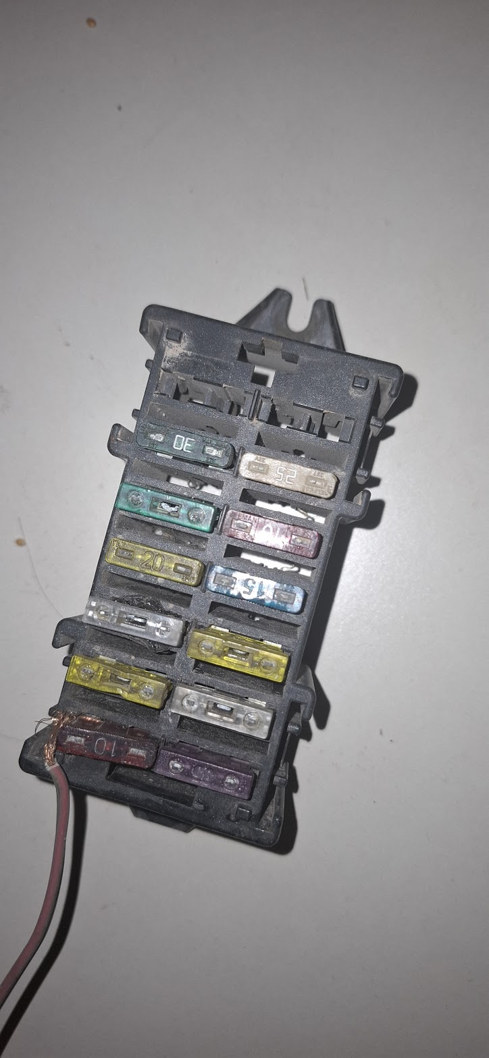
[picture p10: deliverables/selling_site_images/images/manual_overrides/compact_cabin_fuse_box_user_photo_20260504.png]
Compact old-OEM fuse box photo
| Compact cabin fuse box |  |
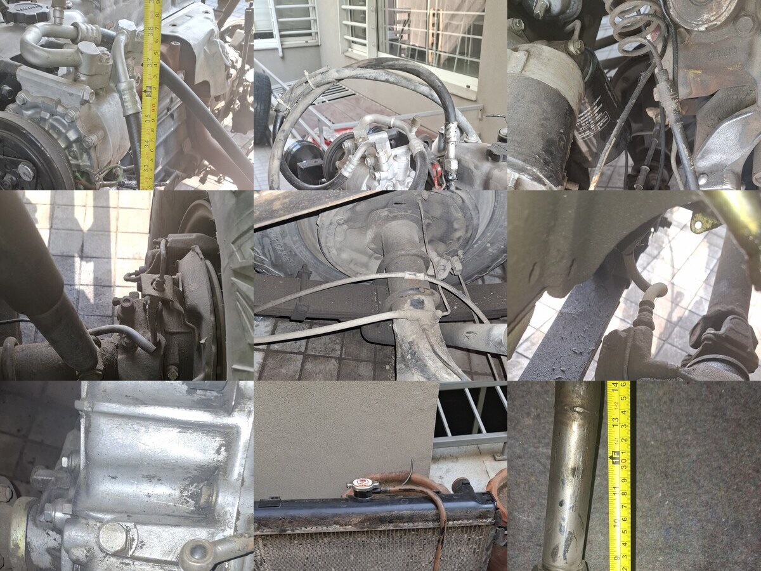
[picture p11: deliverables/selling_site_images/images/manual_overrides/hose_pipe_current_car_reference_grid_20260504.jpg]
Current car hose pipe and fitting crop grid
| Hose, pipe, and fitting overview |  |
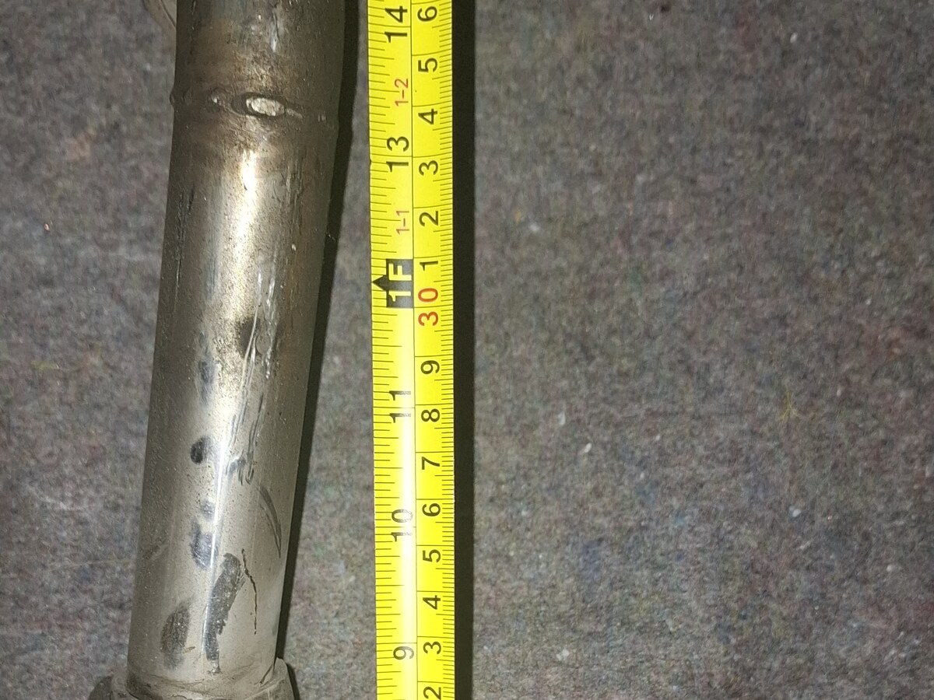
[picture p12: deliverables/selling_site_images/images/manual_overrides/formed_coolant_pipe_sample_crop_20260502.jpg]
Formed coolant pipe sample crop
| Formed metal coolant pipe / connector hoses |  |
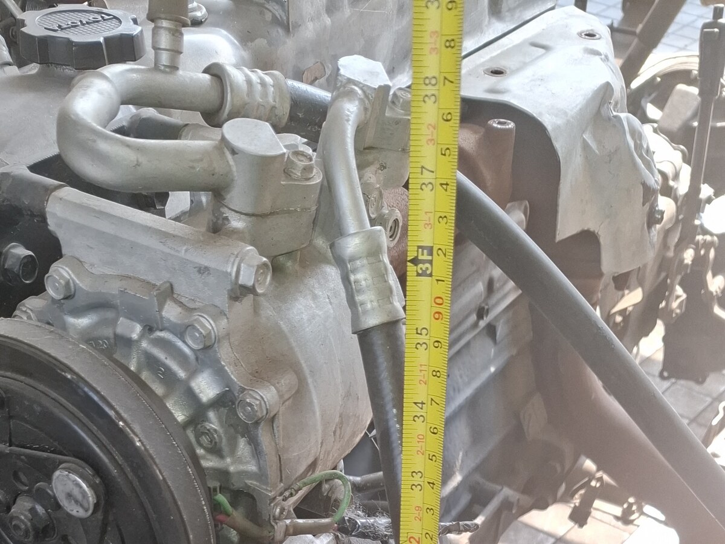
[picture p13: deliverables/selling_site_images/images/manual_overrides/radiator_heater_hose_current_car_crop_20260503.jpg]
Current car radiator and heater hose crop
| Radiator and heater hoses |  |
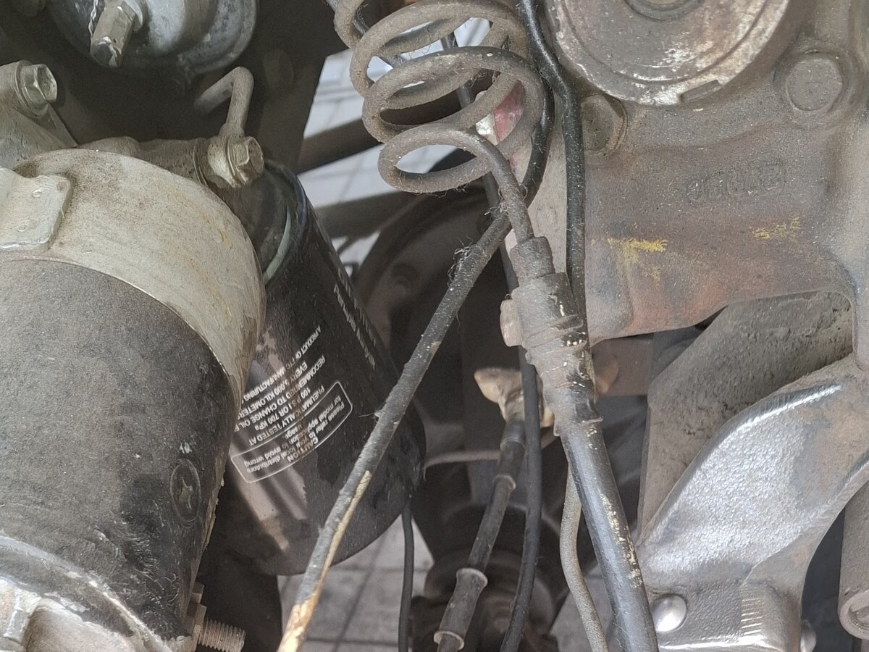
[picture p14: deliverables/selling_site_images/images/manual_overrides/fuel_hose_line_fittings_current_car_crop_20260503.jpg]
Current car fuel hose line and fitting crop
| Fuel hose and line fittings |  |
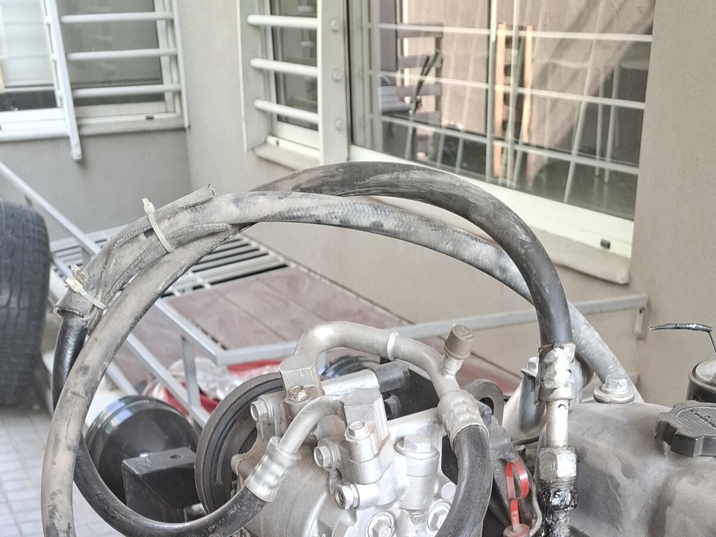
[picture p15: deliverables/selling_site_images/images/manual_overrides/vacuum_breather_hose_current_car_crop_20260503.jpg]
Current car vacuum and breather hose crop
| Vacuum and breather hoses |  |
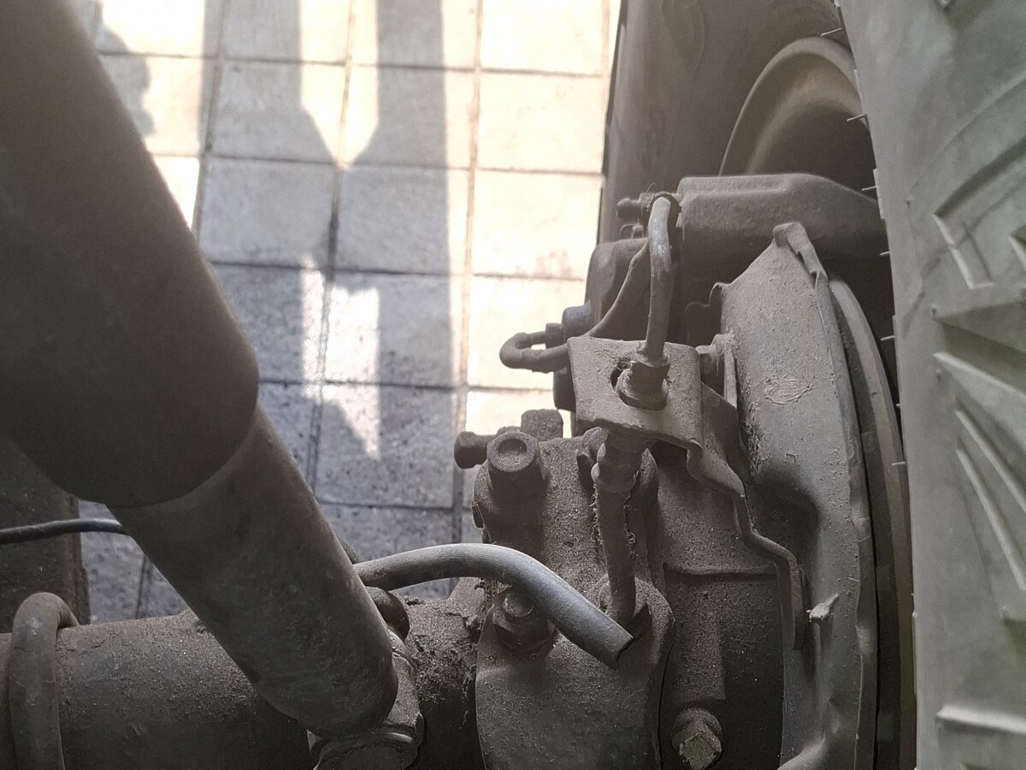
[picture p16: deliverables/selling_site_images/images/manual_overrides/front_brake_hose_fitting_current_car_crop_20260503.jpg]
Current car front brake hose fitting crop
| Brake hydraulic hoses and hard lines |  |
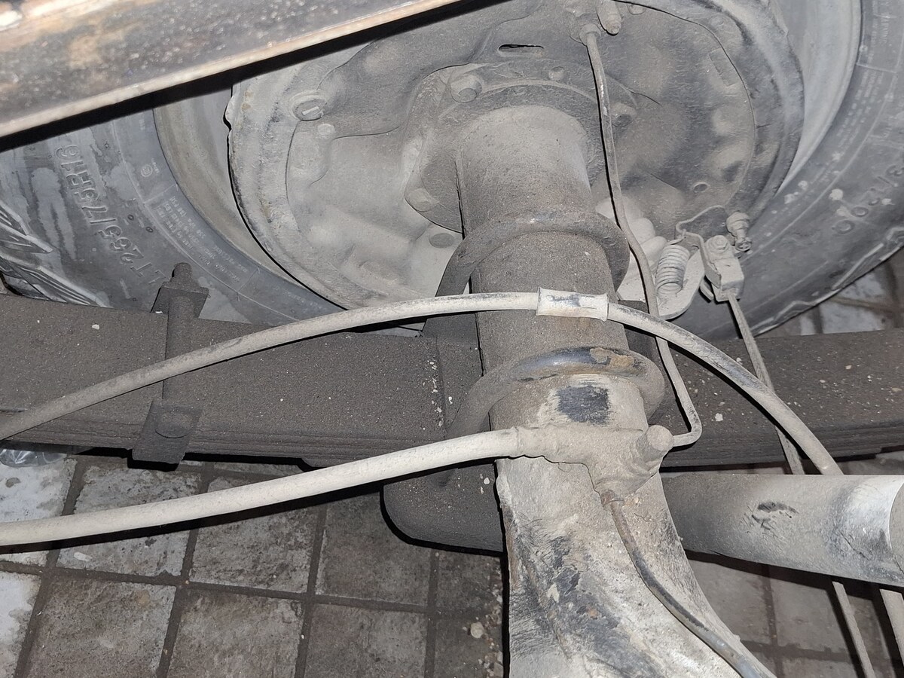
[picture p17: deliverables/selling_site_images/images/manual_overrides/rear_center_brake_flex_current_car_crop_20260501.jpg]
Current car rear brake flex and hard line crop
| Rear brake hard-line and flex context |  |
| Clutch hydraulic line | Current car clutch hydraulic line crop |
| Chassis/body rubbers | Body mount rubber reference |
| Brake booster | Brake booster reference |

## Pipes And Hard Lines

| ID | Component | Qty | Exact market spec | Dimensions / ratings | Must match before final install | Reject |
| --- | --- | ---: | --- | --- | --- | --- |
| `PIPE-COOL-01` | Formed metal coolant/radiator pipe | `1` | Fabricate new from coolant-compatible tube and copy the physical formed coolant pipe sample for bends/clocking/offsets. Mild steel/aluminized steel or 304 stainless, beaded ends. | Buy/quote `1000 mm` tube stock if sold by meter; `750 mm` is the absolute minimum blank. Tube OD `28-30 mm`; wall `1.2-1.6 mm`; bead height `1.5-2.0 mm`; straight clamp lands `25-30 mm` each end. | Trim/bead from the sample, dry-fit, check fan/belt/body clearance, and pressure-test before coating. | Used pipe, no sample copy, no beading tool, no dry-fit before coating. |
| `PIPE-FUEL-01` | Low-pressure diesel feed hard line | Conditional coil/length only if a separate rigid feed line exists | New automotive bundy steel or CuNi/Cunifer tube to replace a confirmed old rigid feed line. Do not duplicate `HOSE-FUEL-01`, which is the measured flexible tank-to-engine feed route. | Conditional stock allowance: `8 mm OD x 5000 mm`; individual sections cut shorter from old rigid route. | Copy old route, unions/end style, clips, pass-through protection, leak test. | Bare copper, plumbing tube, used line, unknown fitting style, or no separate rigid feed line. |
| `PIPE-FUEL-02` | Low-pressure diesel return hard line | `1` coil/length | New automotive bundy steel or CuNi/Cunifer tube to replace the old return line. | Exact stock allowance: `6 mm OD x 5000 mm`; individual sections cut shorter from old route. | Copy old route, unions/end style, clips, pass-through protection, leak test. | Bare copper, plumbing tube, used line, unknown fitting style. |
| `PIPE-BRAKE-01` | Brake hard-line tube and fittings | `1` coil allowance | New brake-rated bundy steel or CuNi/Cunifer only; new brake-rated fittings after flare/thread identification. | `4.75 mm / 3/16 in OD x 7600 mm / 25 ft`. | Old line templates, flare type, fitting thread/seat, individual route lengths, clips, pressure/bleed test. | Bare copper, used line, non-brake fittings, shop cannot identify flare/thread standard. |
| `PIPE-CLUTCH-01` | Clutch hard-line blank | `1` blank allowance | New brake/clutch-rated bundy steel or CuNi/Cunifer. | `4.75 mm / 3/16 in OD x 1500 mm` blank allowance. | Master-to-slave route, port threads, flare/seat style, clips, drivetrain movement. | Bare copper, used line, or unknown flare/thread standard. |
| `CLIP-LINE-01` | Hard-line support clips | On-hand mixed stock plus fasteners | On-hand rubber-lined plated or stainless P-clips plus edge/pass-through protection. | Clip IDs for `4.75 mm`, `6 mm`, and `8 mm` line OD matched to original bracket holes and measured line OD. | Match bracket holes, chafe points, and original hard-line route; add support only where the old route is missing/damaged or unsafe. | Plain cable ties, bare metal clips as permanent support, or moving the route to suit clip stock. |

## Owner Fabrication Tool

This is not part of the hose/pipe shopping table. Add it only if the lines are made at home.

| ID | Tool | Exact requirement | Buy position |
| --- | --- | --- | --- |
| `TOOL-LINE-001` | Brake/fuel hard-line cutter, hand bender, deburrer, and flaring kit | Must cover `4.75 mm / 3/16 in` tube and preferably `6 mm` and `8 mm`; flare type remains held until the old fittings are identified. | Conditional purchase. Do not buy if the brake/hydraulic shop confirms it will cut, bend, deburr, flare, and fit the lines. |

## Hoses

| ID | Component | Qty / buy length | Exact market spec | Dimensions / ratings | Clamp/fitting spec | Reject |
| --- | --- | ---: | --- | --- | --- | --- |
| `HOSE-COOL-01` | Upper radiator hose | `1` new molded hose, `355 mm` | New HJ47/2H upper molded EPDM radiator hose; Toyota `16571-68020`, Dayco `DMH1342` / `CH1342` as accepted shape references. | Published molded free length `355 mm`; order as molded HJ47/2H upper hose because bend shape still controls. | `2` new smooth-band or constant-tension clamps by hose OD. | Used hose, universal straight hose, wrong bend, wrong coolant rating. |
| `HOSE-COOL-02` | Lower radiator hose | `1` new molded hose, `480 mm` | New HJ47/2H lower molded EPDM radiator hose; Toyota `16572-68020`, Dayco `DMH1343` / `CH1343` as accepted shape references. | Published molded free length `480 mm`; order as molded HJ47/2H lower hose because bend shape still controls. | `2` new smooth-band or constant-tension clamps by hose OD. | Used hose, straight hose that kinks, wrong neck size, no coolant rating. |
| `HOSE-COOL-03` | Radiator overflow hose | `1000 mm` | New EPDM coolant/overflow hose from radiator neck to reserve bottle. | Exact buy length `1000 mm`; finished route trims shorter. | New spring clips or smooth-band clamps by OD. | Used hose, clear PVC, washer hose, soft non-coolant hose. |
| `HOSE-COOL-04` | Heater hose stock | `1000 mm` | New EPDM heater hose, SAE J20R3 or better. | Exact buy length `1000 mm`; `16 mm / 5/8 in ID`; cut `400 mm` inlet plus `280 mm` outlet, with remainder as trim allowance. | `4` new smooth-band clamps by hose OD. | Used hose, generic water hose, wrong ID, route kinks. |
| `HOSE-COOL-05A` | Formed pipe connector hose A | `500 mm` | New EPDM radiator/coolant connector blank; straight only if dry-fit does not kink. | Exact blank `500 mm`; `28-30 mm ID`; trim shorter from sample. | `2` new smooth-band or constant-tension clamps. | Used hose or cannot grip beaded pipe/spigot with safe overlap. |
| `HOSE-COOL-05B` | Formed pipe connector hose B | `500 mm` | New connector blank for opposite pipe end. | Exact blank `500 mm`; `28-30 mm ID`; trim shorter from sample. | `2` new smooth-band or constant-tension clamps. | Used hose, straight hose kinks, or unsafe overlap. |
| `HOSE-FUEL-01` | Low-pressure diesel feed hose | `1500 mm` buy length; measured fitted route about `1200 mm` | New diesel-rated hose for the tank/chassis-to-engine feed route, SAE J30R9 preferred; SAE J30R14T2 / DIN 73379-3E acceptable. | `8 mm ID`. | New rolled-edge fuel-injection clamps matched to selected hose OD. | Used hose, no diesel/fuel markings, coolant/vacuum hose, unsupported chassis chafe, perforated clamp. |
| `HOSE-FUEL-02` | Low-pressure diesel return/bleed hose | `2000 mm` | New diesel-rated hose, same rating family as feed. | `6 mm ID`. | New rolled-edge fuel-injection clamps matched to selected hose OD. | Used hose, no fuel marking, washer hose, sharp clamp. |
| `HOSE-FUEL-03` | Injector leak-off hose | `1000 mm` | New braided diesel leak-off hose rated for diesel return service. | `3.2-3.5 mm ID`. | New small fuel clamps only if fitted arrangement requires. | Used hose, vacuum/washer/coolant/unmarked small hose. |
| `HOSE-VAC-01` | Brake-booster vacuum hose | `2000 mm` | New reinforced oil-resistant vacuum hose that will not collapse. | Exact buy length `2000 mm`; `10-12 mm ID`; trim to pump/check-valve/booster route. | New smooth-band clamps by hose OD; correct check-valve direction. | Used hose, thin soft washer hose, coolant hose, collapses under vacuum. |
| `HOSE-BREATHER-01` | Crankcase breather/oil-mist hose | `1000 mm` | New NBR/fuel/oil-rated or oil-mist-rated hose. | Exact buy length `1000 mm`; `16-19 mm ID`; trim to breather route. | New smooth-band clamps by hose OD. | Used hose or coolant-only EPDM where oil mist is present. |
| `HOSE-BRAKE-01` | Brake flex hose assemblies | `3` new complete assemblies | New front left, front right, and rear center frame-to-axle complete crimped brake hoses. | Free length copied from old samples; end threads/banjo/seats and bracket grooves copied exactly. | New DOT/SAE J1401 or OEM-equivalent assemblies only. | Used hose, hose cut from roll, unknown rating, unmatched ends. |
| `HOSE-CLUTCH-01` | Clutch flex hose | `1` new complete assembly | New complete crimped hydraulic clutch/brake hose assembly. | Free length/end threads/seat/bracket groove copied from sample. | New brake/clutch hydraulic-rated assembly. | Used hose, generic rubber hose, or wrong fitting. |

## Brake And Control Cables

Old cables are length/end samples only. Any cable bought for final installation must be a new assembly.

| ID | Component | Qty / buy length | Exact market spec | Dimensions / ratings | Must match | Reject |
| --- | --- | ---: | --- | --- | --- | --- |
| `CABLE-BRAKE-01` | Rear parking-brake / handbrake cable set | `1` left/right set | New rear parking-brake cable assemblies with corrosion-protected outer sheaths, plus new clevis pins, clips, return springs, and adjuster hardware as fitted. | Final length comes from removed old samples measured in `mm`: overall cable length, sheath length, backing-plate end, equalizer/intermediate end, bracket/clip positions, adjuster thread and travel. | Rear drum backing-plate levers, equalizer/intermediate linkage, original route, and support clips. | Used cable, frayed/seized cable, unknown end style, wrong sheath length, missing adjuster/clip hardware, or catalog-only match without the old sample. |
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

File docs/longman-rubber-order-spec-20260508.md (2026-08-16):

# Longman Rubber Order Spec - 2026-05-08

> **Superseded for supplier use on 2026-07-26.** Use
> `docs/rubber-manufacturer-order-spec-20260726.md`. The current supplier
> order contains only body pads, front-support oval pads, and underfloor
> strips. Hoses and bump stops are excluded.

Purpose: send one consolidated custom-rubber manufacturing request to Longman for the current J40 body/front-support/chassis rubber batch, with the bump-stop rubber updated to match the May 31 exact front-stop photos and the May 29 removed-fixture support photos.

Supplier fit: Longman Mills lists custom rubber parts, automobile parts, rubber-to-metal bonded parts, hose pipes, and rubber testing capability, so this pack asks them to quote the rubber pieces and advise what samples or steel inserts they need before final production.

Longman site references:

- https://www.longman.com.pk/
- https://www.longman.com.pk/products/
- https://www.longman.com.pk/about-us/
- https://www.longman.com.pk/automobile-parts/

## Release Position - 2026-05-29

The old-rubber photos and ruler measurements are accepted as the dimensional basis for quote and first articles. The remaining open items are station fit and stack-release checks, not missing rubber dimensions.

May 17 loose-strip ruler photos show the underfloor strip length at about `16.5 in` (`419 mm`), so the `FS-STRIP-L/R` first-article length is corrected to `420 mm`. Width and thickness remain `38 W x 8 T mm`; any end trim, holes, slots, bonding, or retainer remake still requires dry-fit or a direct retainer trace.

Use this distinction:
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

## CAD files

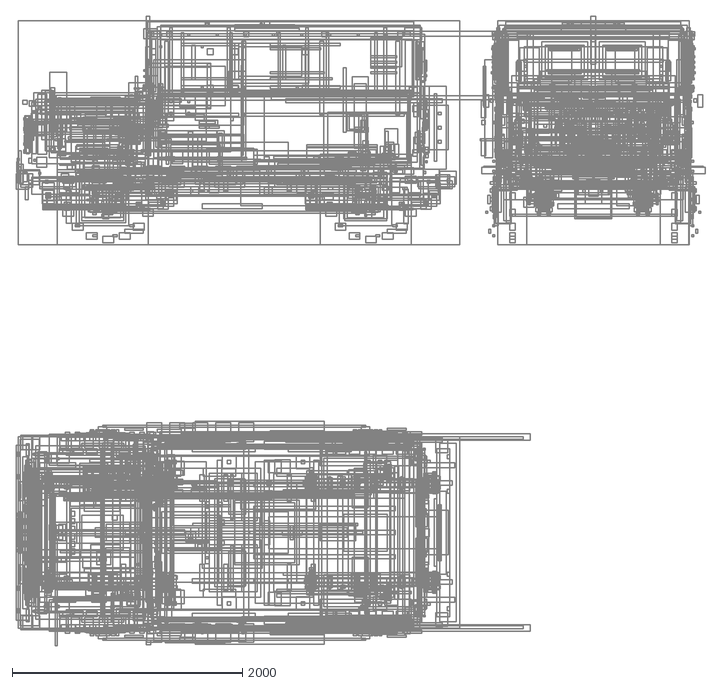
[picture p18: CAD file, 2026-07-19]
data/manual/cad/j40_reference_model/04_exports/scaffold_rev_c/j40_full_vehicle_scaffold_rev_c_orthographic.dxf
5988.0 x 5475.0

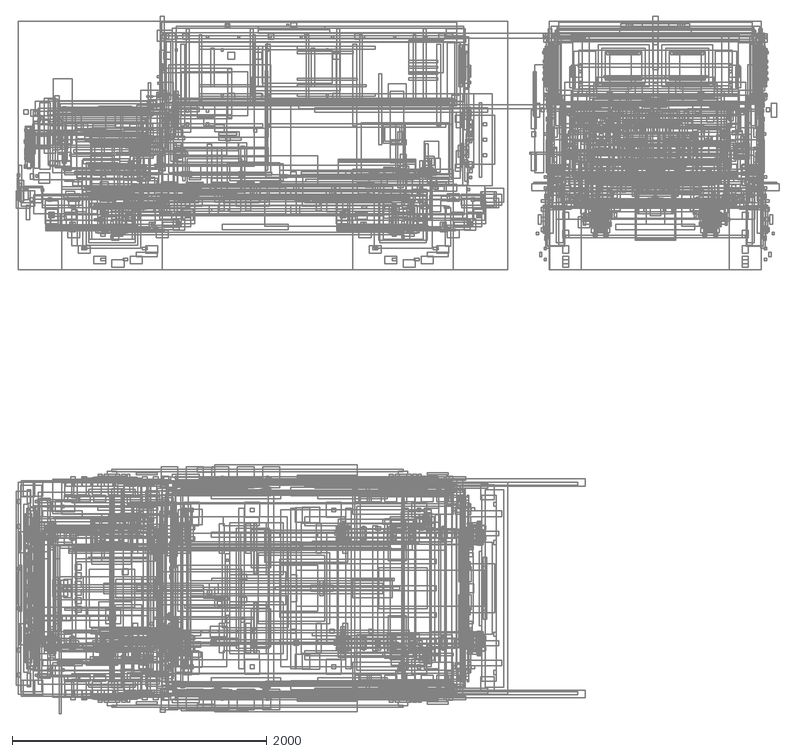
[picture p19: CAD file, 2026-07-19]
data/manual/cad/j40_reference_model/04_exports/scaffold_rev_c_lhd_review/j40_full_vehicle_scaffold_rev_c_lhd_review_orthographic.dxf
5988.0 x 5475.0

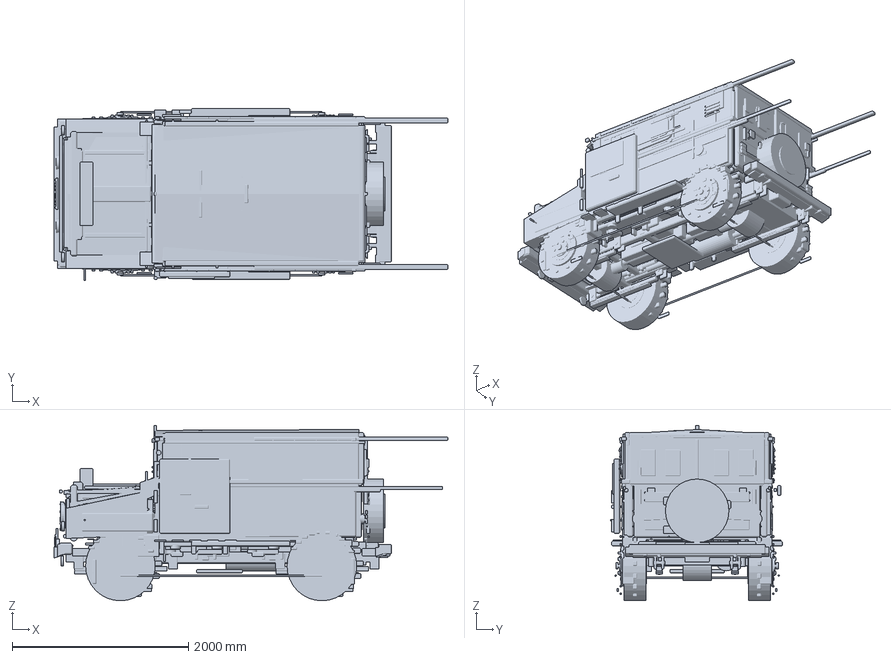
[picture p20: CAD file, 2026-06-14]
data/manual/cad/j40_reference_model/04_exports/scaffold_rev_c/j40_full_vehicle_scaffold_rev_c_3d_autocad.dxf
4468.0 x 1955.0 x 1990.0 mm

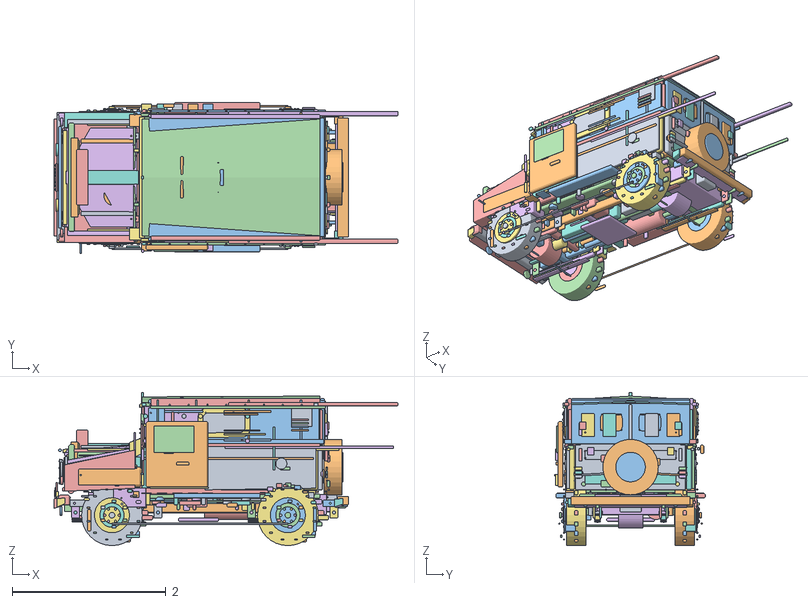
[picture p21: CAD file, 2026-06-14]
data/manual/cad/j40_reference_model/04_exports/scaffold_rev_c_lhd_review/j40_full_vehicle_scaffold_rev_c_lhd_review_editable.obj
4.47 x 1.96 x 1.99
j40_rt_001_drive_and_drivetrain_orientation_engine_gearbox_transfer_centerline
j40_rt_001_drive_and_drivetrain_orientation_front_output_to_front_pinion
j40_rt_001_drive_and_drivetrain_orientation_rear_output_to_rear_pinion
j40_rt_002_battery_positive_to_cutoff_battery_to_cutoff_sweep
j40_rt_003_cutoff_output_to_relay_box_feed_cutoff_to_relay_feed
j40_rt_004_cutoff_output_to_midi_common_feed_cutoff_to_midi_common
j40_rt_005_midi_five_output_fanout_midi_output_fanout
j40_rt_006_battery_negative_engine_chassis_body_grounds_battery_negative_to_engine
j40_rt_006_battery_negative_engine_chassis_body_grounds_body_chassis_ground_strap
j40_rt_007_starter_main_and_solenoid_trigger_starter_main_cable
j40_rt_007_starter_main_and_solenoid_trigger_starter_solenoid_trigger
j40_rt_008_alternator_charge_regulator_branch_alternator_charge_branch
j40_rt_009_engine_sender_injection_pump_branch_engine_sender_injection_pump_branch
j40_rt_010_headlamp_marker_horn_aux_lamp_branch_front_lamp_cross_loom
j40_rt_011_compressor_clutch_pressure_switch_condenser_fan_branch_compressor_pressure_fan_branch
j40_rt_012_under_dash_evaporator_blower_controls_feed_under_dash_evaporator_feed
j40_rt_013_firewall_main_pass_throughs_main_firewall_pass_through_band
j40_rt_014_rear_body_tail_fuel_sender_loom_rear_body_tail_fuel_sender_loom
j40_rt_015_front_brake_hard_lines_and_flex_hoses_front_brake_master_to_crossmember
j40_rt_015_front_brake_hard_lines_and_flex_hoses_front_brake_flex_sweep_left
j40_rt_015_front_brake_hard_lines_and_flex_hoses_front_brake_flex_sweep_right
j40_rt_016_rear_axle_hard_lines_center_flex_and_wheel_cylinder_lines_rear_axle_brake_pipe_and_center_flex
j40_rt_017_parking_brake_cables_equalizer_and_clips_parking_brake_equalizer_to_axle
j40_rt_018_fuel_supply_return_leakoff_and_sender_routes_fuel_supply_return_frame_pair
j40_rt_019_filler_neck_vent_and_tank_access_filler_neck_and_vent_pair
j40_rt_020_compressor_discharge_to_condenser_ac_discharge_compressor_to_condenser
j40_rt_021_condenser_to_receiver_drier_liquid_line_ac_condenser_to_drier_liquid_line
j40_rt_022_drier_to_evaporator_and_evaporator_suction_to_compressor_ac_firewall_to_evaporator_suction_pair
j40_rt_023_radiator_heater_overflow_and_bypass_hoses_radiator_heater_overflow_hose_bundle
j40_rt_024_throttle_choke_fuel_stop_and_heater_control_cables_throttle_choke_fuel_stop_control_cables
j40_rt_025_speedometer_cable_and_transfer_gear_route_speedometer_cable_cluster_to_transfer
j40_rt_026_evaporator_condensate_and_body_drain_routes_evaporator_condensate_drain
j40_rt_027_exhaust_route_and_hanger_clearance_exhaust_heat_route_reference
j40_rt_028_p_clips_tabs_grommets_and_loom_guards_routing_supports_spine
j40_rt_028_p_clips_tabs_grommets_and_loom_guards_shared_route_support_1_clip
j40_rt_028_p_clips_tabs_grommets_and_loom_guards_shared_route_support_2_clip
j40_rt_028_p_clips_tabs_grommets_and_loom_guards_shared_route_support_3_clip
j40_rt_028_p_clips_tabs_grommets_and_loom_guards_shared_route_support_4_clip
j40_rt_028_p_clips_tabs_grommets_and_loom_guards_shared_route_support_5_clip
j40_rt_028_p_clips_tabs_grommets_and_loom_guards_shared_route_support_6_clip
j40_rt_028_p_clips_tabs_grommets_and_loom_guards_shared_route_support_7_clip
j40_rt_028_p_clips_tabs_grommets_and_loom_guards_shared_route_support_8_clip
j40_rt_028_p_clips_tabs_grommets_and_loom_guards_shared_route_support_9_clip
floor_pan
left_rocker_sill
right_rocker_sill
left_rear_quarter_panel
right_rear_quarter_panel
tailgate_panel
firewall
cowl_top
grille_panel
hood_closed_reference
hood_crowned_closed_skin
hood_front_rolled_lip_surface
hood_left_hinge_axis
hood_right_hinge_axis
left_front_fender
right_front_fender
left_inner_fender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

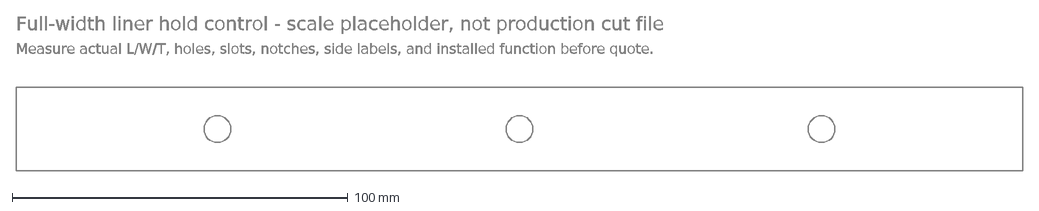
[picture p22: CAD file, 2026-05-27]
data/manual/fabrication/rubber_recreation_rev_a/body_liner_full_width_hold_control.dxf
Full-width liner hold control - scale placeholder, not production cut file
Measure actual L/W/T, holes, slots, notches, side labels, and installed function before quote.

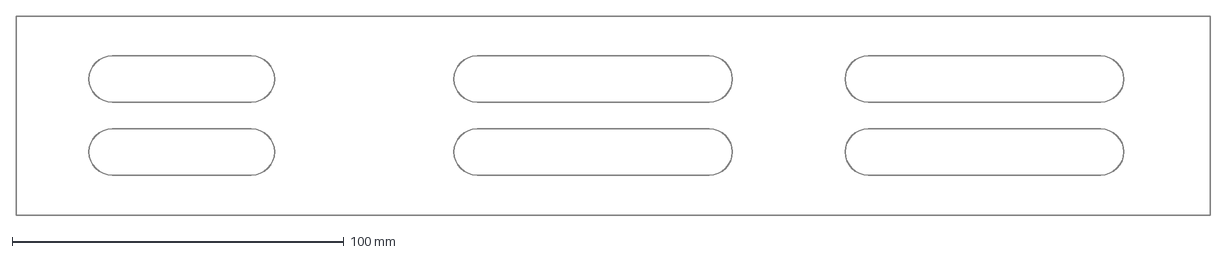
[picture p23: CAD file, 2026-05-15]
data/manual/fabrication/battery_power_carrier_mount_rev_a/battery_stand_adjustable_offset_bar_rev_b.dxf
360.0 x 60.0 mm

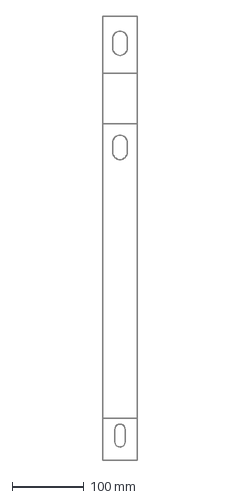
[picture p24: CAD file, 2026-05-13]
data/manual/fabrication/front_radiator_two_side_retention_rev_a/front_radiator_saddle_right_angle_post_rev_a.dxf
48.0 x 618.0 mm

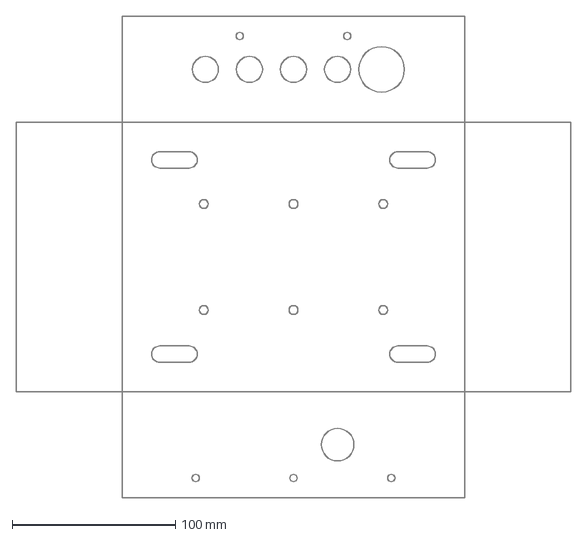
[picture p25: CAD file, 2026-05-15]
data/manual/fabrication/midi5_enclosure_rev_d/midi5_enclosure_body_rev_d.dxf
340.0 x 295.0 mm

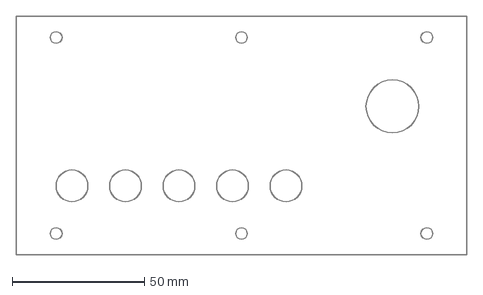
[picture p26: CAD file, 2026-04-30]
data/manual/fabrication/midi5_module_rev_b/midi5_module_rear_insulator_rev_b.dxf
170.0 x 90.0 mm

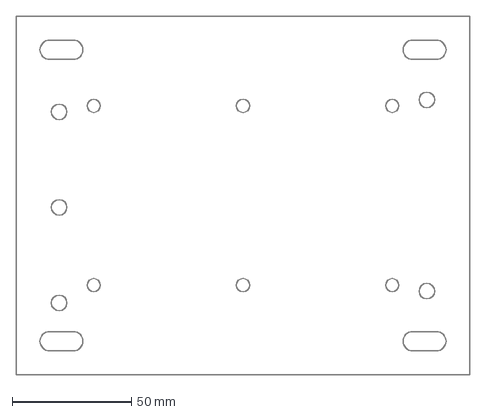
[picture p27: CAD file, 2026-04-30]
data/manual/fabrication/midi5_plate_mount_rev_c/midi5_mount_plate_rev_c.dxf
190.0 x 150.0 mm

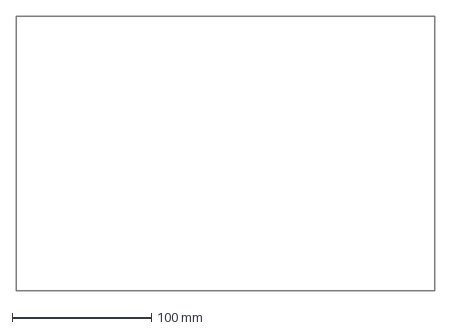
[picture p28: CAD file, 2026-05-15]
data/manual/fabrication/relay_mount_rev_d/relay_insulating_sheet_rev_d.dxf
300.0 x 197.0 mm

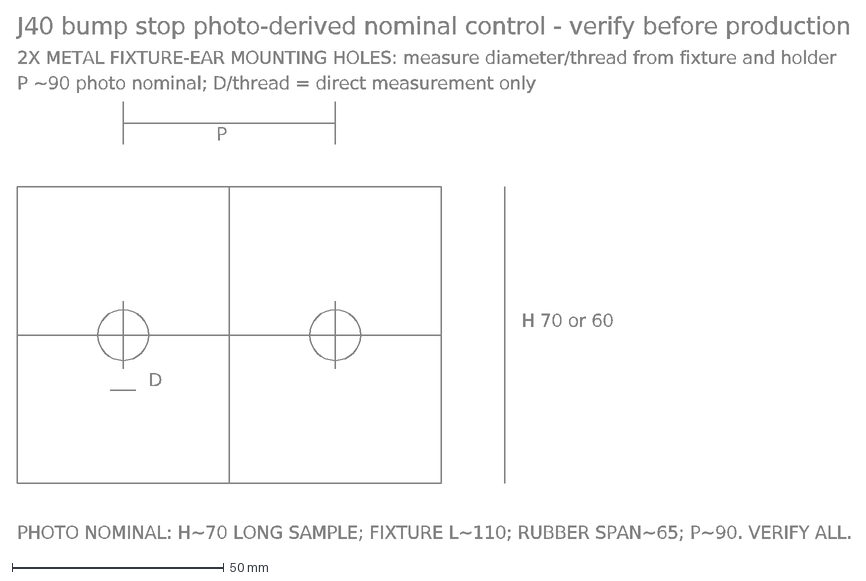
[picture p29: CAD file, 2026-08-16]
data/manual/fabrication/rubber_recreation_rev_a/bump_stop_vehicle_measurement_control.dxf
J40 bump stop photo-derived nominal control - verify before production
2X METAL FIXTURE-EAR MOUNTING HOLES: measure diameter/thread from fixture and holder
P ~90 photo nominal; D/thread = direct measurement only
PHOTO NOMINAL: H~70 LONG SAMPLE; FIXTURE L~110; RUBBER SPAN~65; P~90. VERIFY ALL.
P
D
H 70 or 60

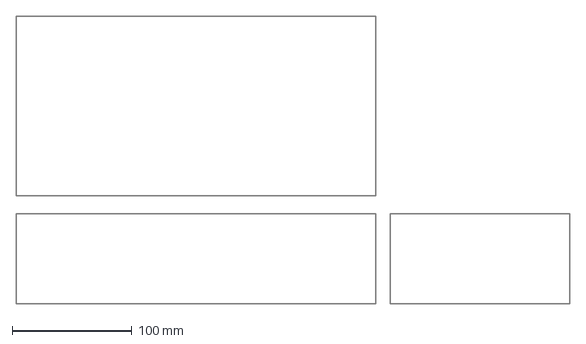
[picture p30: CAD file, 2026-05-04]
data/manual/fabrication/suspension_wood_cribbing_rev_a/swc_rectangular_cribbing_block_rev_a.dxf
462.0 x 240.0 mm

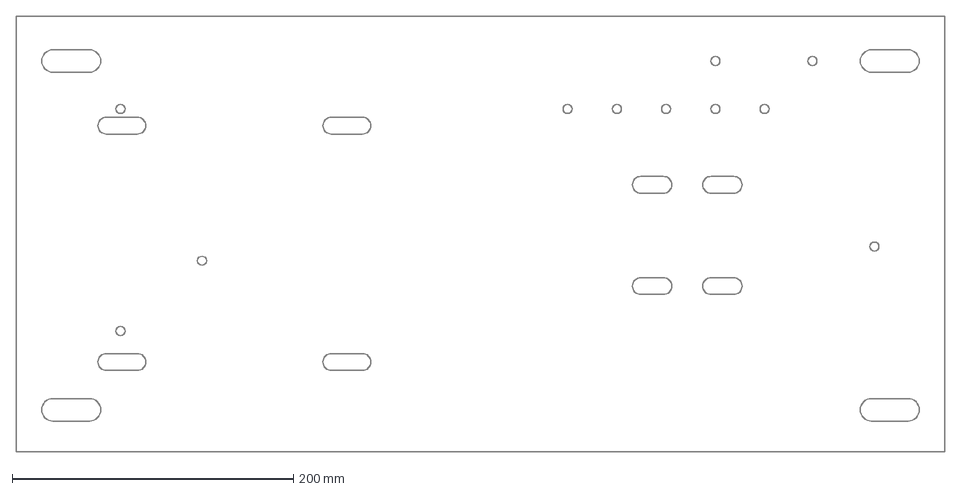
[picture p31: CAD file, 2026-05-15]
data/manual/fabrication/battery_power_carrier_mount_rev_a/battery_power_compact_front_service_rail_rev_b.dxf
660.0 x 310.0 mm

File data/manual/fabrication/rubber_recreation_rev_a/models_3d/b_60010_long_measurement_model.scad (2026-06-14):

// BUMP-60010 rear/back long stop model, same front shape
// J40 rubber recreation 3D model, units: millimetres.
// Generated by tools/generate_rubber_recreation_3d_models.py.
// OpenSCAD is the source model; export STL only after release parameters are set.

$fn = 64;

module rounded_rect_2d(size, r) {
  hull() {
    translate([-(size[0] / 2 - r), -(size[1] / 2 - r)]) circle(r = r);
    translate([ (size[0] / 2 - r), -(size[1] / 2 - r)]) circle(r = r);
    translate([ (size[0] / 2 - r),  (size[1] / 2 - r)]) circle(r = r);
    translate([-(size[0] / 2 - r),  (size[1] / 2 - r)]) circle(r = r);
  }
}

module capsule_2d(length, width) {
  hull() {
    translate([-(length - width) / 2, 0]) circle(d = width);
    translate([ (length - width) / 2, 0]) circle(d = width);
  }
}

module chamfered_extrude(height, edge_chamfer = 0) {
  eps = 0.01;
  if (edge_chamfer <= 0) {
    linear_extrude(height = height, center = false)
      children();
  } else {
    union() {
      translate([0, 0, edge_chamfer])
        linear_extrude(height = height - (2 * edge_chamfer), center = false)
          children();

      hull() {
        translate([0, 0, 0])
          linear_extrude(height = eps, center = false)
            offset(delta = -edge_chamfer)
              children();
        translate([0, 0, edge_chamfer])
          linear_extrude(height = eps, center = false)
            children();
      }

      hull() {
        translate([0, 0, height - edge_chamfer])
          linear_extrude(height = eps, center = false)
            children();
        translate([0, 0, height - eps])
          linear_extrude(height = eps, center = false)
            offset(delta = -edge_chamfer)
              children();
      }
    }
  }
}

// Vehicle-measurement model:
// - Height is the known Toyota-family control.
// - May 31 exact front-stop photos now control the visible body shape:
//   broad rounded/tapered rubber body on a metal/fixture base plate,
//   two end bolt holes in that base/fixture, and a flat strike area.
// - Rear/back stops use the same front-stop shape and fixture pattern at the
//   longer Toyota-family height.
// - Final body footprint, base-hole pitch/diameter, fixture interface, and
//   strike offset must be confirmed from sample calipers, removed metal fixture,
//   cleaned vehicle bracket, and axle strike pad.
// - This model is a first-article conversation shape, not a released mould.

module b_60010_long_measurement_model(
  free_height = 70,
  top_length = 70,
  top_width = 38,
  rubber_base_length = 92,
  rubber_base_width = 52,
  base_plate_length = 128,
  base_plate_width = 58,
  base_plate_thickness = 6,
  base_hole_pitch = 100,
  base_hole_d = 14,
  strike_face_depth = 2
) {
  union() {
    color([0.42, 0.28, 0.20])
      difference() {
        linear_extrude(height = base_plate_thickness, center = false)
          capsule_2d(base_plate_length, base_plate_width);

        if (base_hole_d > 0 && base_hole_pitch > 0)
          for (x = [-base_hole_pitch / 2, base_hole_pitch / 2])
            translate([x, 0, -1])
              cylinder(h = base_plate_thickness + 2, d = base_hole_d);
      }

    color("black")
      hull() {
        translate([0, 0, base_plate_thickness + 0.5])
          linear_extrude(height = 1, center = false)
            rounded_rect_2d([rubber_base_length, rubber_base_width], 10);
        translate([0, 0, base_plate_thickness + free_height - 1])
          linear_extrude(height = 1, center = false)
            rounded_rect_2d([top_length, top_width], 8);
      }

    color([0.17, 0.18, 0.16])
      translate([0, 0, base_plate_thickness + free_height])
        linear_extrude(height = strike_face_depth, center = false)
          rounded_rect_2d([top_length, top_width], 8);
  }
}

b_60010_long_measurement_model();

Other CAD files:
data/manual/fabrication/dashboard_lcd_hvac_fascia_rev_h/full_width_fascia_master_rev_h.dxf
data/manual/cad/j40_reference_model/04_exports/scaffold_rev_c/j40_full_vehicle_scaffold_rev_c_editable.obj
data/manual/cad/j40_reference_model/04_exports/scaffold_rev_c_lhd_review/j40_full_vehicle_scaffold_rev_c_lhd_review_3d_autocad.dxf
data/manual/fabrication/dashboard_lcd_hvac_fascia_rev_h/full_width_fit_template_rev_h.dxf
data/manual/fabrication/rubber_recreation_rev_a/models_3d/b_60010_rear_pair_measurement_model.scad
data/manual/fabrication/rubber_recreation_rev_a/models_3d/b_60020_short_measurement_model.scad
data/manual/fabrication/rubber_recreation_rev_a/models_3d/bm_iso_lg_square_pad.scad
data/manual/cad/j40_reference_model/04_exports/scaffold_rev_a/j40_full_vehicle_scaffold_rev_a.scad
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

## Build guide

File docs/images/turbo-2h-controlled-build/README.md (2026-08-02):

# 2H Controlled Turbo Build Visuals

Generated planning visuals for `docs/2h-turbo-recommended-build-process-20260801.md`.

These images are process and packaging aids only. They are not dimensional drawings, as-built records, component-identification evidence or authority to fabricate. Physical parts and measured vehicle clearances control every release gate.

Included assets:

- `01-package-receipt-inspection.png` — Stage 3 goods-receipt and identity-control concept.
- `02-full-engine-bay-mockup.png` — Stages 4–6 full-vehicle mock-up and clearance concept.
- `03-static-commissioning.png` — Stages 10–12 static test and monitoring concept.
- `04-known-components-relocation-study.png` — fuller retained/new component packaging study used with the relocation matrix.
- `05-rev-h-radiator-battery-electrical-packaging.png` — earlier Rev H relocation study using cardboard component envelopes; retained as visual history.
- `06-real-components-rev-h-packaging-near-side.png` — current near-side packaging study using the photographed round steel air cleaner, DLS120 battery, cutoff, relay enclosure and MIDI fuse bank. It removes the unused compact-air-cleaner alternative and provisional side/wing cooler because charge cooling is contained in the Rev H front stack.
- `07-real-components-rev-h-packaging-opposite-side.png` — paired opposite-side view of the same controlled layout, generated as a camera move rather than a mirrored image.
- `08-real-components-j80-steering-near-side.png` — updated near-side packaging study with a conceptual RHD J80 box, matched pitman/drag-link route, collapsible shaft, 2H pump, reservoir and hoses. The DLS120 remains in its current/as-photographed orientation.
- `09-real-components-j80-steering-opposite-side.png` — opposite-front-wing companion view of the same J80-controlled packaging state.
- `10-polished-complete-plumbing-j80-near-side.png` — finished near-side concept with practical polished aluminium/stainless/copper surfaces and visibly completed intake, charge-air, turbo service, cooling, J80 steering, A/C, vacuum, fuel and electrical routes.
- `11-polished-complete-plumbing-j80-opposite-side.png` — opposite-side companion showing the same finished plumbing state and retained battery/J80 packaging relationships.
- `12-purchased-scale-electrical-near-side.png` — near-side refinement that sizes the purchased relay enclosure at its approximately `300 x 197 mm` footprint on a separate `360 x 245 mm` carrier and protects the five-way MIDI bank in an approximately `210 x 165 x 65 mm` hinged enclosure.
- `13-purchased-scale-electrical-opposite-side.png` — opposite-side companion showing the same larger, separately supported relay and MIDI assemblies and their protected cable exits.
- `14-front-aligned-radiator-holder-bars.png` — corrected near-side view with the radiator square and centered in the front grille/core-support plane and the two existing welded radiator holder bars restored at the sides.
- `15-front-aligned-radiator-annotated.png` — labelled companion to image 14 with deterministic leader lines identifying 18 major visible components and systems.
- `15-front-aligned-radiator-annotated.svg` — editable source for the annotated image.
- `16-polished-engine-side-exhaust-manifold.png` — image 14 refined by changing the long dull engine-side exhaust manifold and turbo-entry runner to polished stainless steel while retaining their routing and all radiator, holder-bar, plumbing and packaging relationships.
- `17-bonnet-clear-radiator-brackets.png` — image 16 refined by removing the unexplained cone-shaped objects and lowering both existing radiator brackets to compact upper mounts beneath the bonnet-closing envelope.

Image 17 is the current near-side visual authority for radiator alignment, bonnet-clear holder brackets, finish, plumbing and electrical-box packaging discussions; image 15 remains the identification aid for the preceding image-14 state. Image 13 remains the latest opposite-side companion. Images 10–12, 14 and 16 remain preceding finished states; images 08 and 09 remain the underlying J80 packaging studies; images 04–07 remain development history.

The approximately `300 x 205 mm` DLS120 footprint fits the proposed `340 x 265 mm` tray in the baseline orientation. Rotating only the battery on the unchanged tray fails because its `300 mm` dimension exceeds the tray's `265 mm` short side by `35 mm`. A whole-carrier turn would demand an approximately `265 x 340 mm` bay envelope and remains held pending two-axis cavity, bonnet/terminal, cable, hold-down, lift-out and J80-steering clearance measurements. The relay enclosure footprint is therefore nearly the same size as the battery footprint; the current visuals intentionally avoid depicting it as a small accessory box. The MIDI dimensions describe its proposed protective enclosure, not just the five linked red holders. The depicted electrical positions, J80 hardware and plumbing remain packaging concepts, not dimensional proof or fabrication evidence. Bonnet height, connector access, cable bend radius, lift-out and bracket loads require confirmation with the purchased parts in a physical mock-up. Final hose ends, diameters, lengths, heat protection and supports likewise require confirmed parts and physical mock-up.

Generation mode: OpenAI built-in image generation.

The source prompt set is recorded in `generation-prompts.md`.

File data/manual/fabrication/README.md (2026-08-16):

# J40 Fabrication Output Index

This directory contains the repo-native fabrication packages that can be sent to a local fabricator or used for first-article review.

All dimensional packages use millimetres. Send the `DXF` files for CAD/CAM cutting, the `SVG` files for quick visual review where present, the package PDF for non-CAD review, and the `*_3d_visualisation.html` files when a browser-based assembly read is useful.

## Current Release Packages

| Package | Workstream | Status | Primary PDF | Notes |
| --- | --- | --- | --- | --- |
| `dashboard_lcd_hvac_fascia_rev_i` | Dashboard / infotainment / A/C HVAC | Purchased Pioneer DMH-AP6650BT incorporated into the owner-selected V35 centre-cassette target; CNC quotation plus full-size/full-depth disposable template only; production geometry and cutting held for M1-M9, with M10 required before commissioned vehicle handoff | `dashboard_lcd_hvac_fascia_rev_i/README.md` | Centre-only removable cassette replacing the ashtray area while the OEM outer fascia, formed contours, large asymmetric plate-and-knob glovebox, complete Toyota speedometer and factory RHD column scallop remain unchanged. The cassette carries the purchased 9-inch Pioneer receiver and a single line of seven bought selectors plus separate red Hazard; exactly two high outer/end chrome/silver outlets are separate retained-panel operations. Published 188 x 108 x 37 mm main-chassis dimensions inform the depth study, but the exact screen face, mount, connector and complete service envelope remain held for M4/M5 measurement and M9 buck proof. |
| `rubber_recreation_rev_a` | Chassis rubbers | Quote and first article ready; final production has station-fit gates | `rubber_recreation_rev_a/j40_rubber_recreation_rev_a_dimension_sheet.pdf` | Square body-pad 3D controls, cup washer blanks, oval front-support pad, and released plain underfloor strip drawings. |
| `suspension_wood_cribbing_rev_a` | Suspension setup | Fabrication complete and closed; retained reference package | `suspension_wood_cribbing_rev_a/j40_suspension_wood_cribbing_rev_a_dimension_sheet.pdf` | Received hardwood cribbing blocks and exact wedge chocks for suspension/brake support setup; includes interactive 3D visualisation. |
| `na_cooling_connector_arms_rev_p` | Fabrication / radiator / chassis fixing / A/C HVAC | Current measured and structural release HOLD | `na_cooling_connector_arms_rev_p/README.md` | Naturally aspirated package: matched connector-sized A0 arms, lower cradle, separate G0 removable-guard and radiator holders, independent carriers, one FS front A/C pusher and one FL rear puller. CL0 directly holds the complete G0 perimeter frame, FS frame/rotor datum and C0 usable-fin-field centreline within ±2 mm laterally of VCL; G0-to-fixed-body-aperture and FS-to-C0 local X/Z checks are separate and must not be tolerance-stacked. Final material and geometry await signed measurements and structural release. |
| `front_cooling_stack_rev_a` | Fabrication / radiator / A/C HVAC | Historical turbo-era mock-up; superseded by Rev P | `front_cooling_stack_rev_a/README.md` | Retained for provenance only. Do not use its full-height uprights, turbo/intercooler architecture or fan arrangement for current fabrication or procurement. |
| `midi5_enclosure_rev_d` | Electrical reset | Current recommended MIDI holder enclosure | `midi5_enclosure_rev_d/j40_midi5_enclosure_rev_d_dimension_sheet.pdf` | Folded aluminium box with hinged lid, insulating subplate, one fuse-4 input grommet, five output grommets, and enlarged far-side double-cable output hole; includes interactive 3D visualisation. |
| `relay_mount_rev_d` | Electrical reset | Current recommended relay-box base | `relay_mount_rev_d/j40_relay_mount_rev_d_dimension_sheet.pdf` | Simplified relay support: flat aluminium base plate plus exact relay-bottom-footprint insulating sheet under the existing relay box's large uncovered bottom face; includes interactive 3D visualisation. |
| `battery_power_carrier_mount_rev_a` | Fabrication / chassis fixing / electrical reset | Prototype/mock-up release for chassis-mounted battery stand and integrated relay/fuse/cutoff carrier | `battery_power_carrier_mount_rev_a/j40_battery_power_carrier_mount_rev_a_dimension_sheet.pdf` | Formed chassis saddle/upright bridge with configurable body-side offset bars, full-height battery support tray/deck, hold-down crossbar, raised front/radiator-side service ladder, vertical Relay Rev D flat base/insulator directly attached to the main sheet, top-front MIDI Rev D enclosure shelf, side-mounted 100A breaker/cutoff base/guard, battery-to-cutoff and cutoff-to-relay/MIDI cable paths, and 3D visualisation files. |

## Superseded Dashboard Packages

| Package | Status | Replacement |
| --- | --- | --- |
| `dashboard_lcd_hvac_fascia_rev_g` | Superseded four-outlet quotation/template record; do not use its V1-V4 apertures, coordinates or duct schedule for the current job | `dashboard_lcd_hvac_fascia_rev_i` |

## Reference / Fallback Electrical Packages

| Package | Workstream | Status | Primary PDF | Notes |
| --- | --- | --- | --- | --- |
| `relay_mount_rev_c` | Electrical reset | Superseded fallback standalone relay-box mount | `relay_mount_rev_c/j40_relay_mount_rev_c_dimension_sheet.pdf` | Folded aluminium relay carrier plus plastic rear guard; use only if the Rev D flat-base route is deliberately rejected; includes interactive 3D visualisation. |

## Superseded Electrical Packages

| Package | Status | Replacement |
| --- | --- | --- |
| `midi5_module_rev_a` | Superseded boxed MIDI module | `midi5_enclosure_rev_d` |
| `midi5_module_rev_b` | Superseded boxed MIDI module | `midi5_enclosure_rev_d` |
| `midi5_plate_mount_rev_c` | Superseded open MIDI plate | `midi5_enclosure_rev_d` |
| `relay_mount_rev_c` | Superseded folded relay carrier | `relay_mount_rev_d` |

## Generator Scripts

- `tools/generate_rubber_recreation_fabrication_pack.py`
- `tools/generate_suspension_wood_cribbing_rev_a.py`
- `tools/generate_front_radiator_two_side_retention_rev_a.py`
- `tools/generate_midi5_plate_mount_rev_c.py`
- `tools/generate_midi5_enclosure_rev_d.py`
- `tools/generate_relay_mount_rev_c.py`
- `tools/generate_relay_mount_rev_d.py`
- `tools/generate_fabrication_3d_visualisations.py`
- `tools/generate_battery_power_carrier_mount_rev_a.py`
- `tools/generate_dashboard_lcd_hvac_fascia_rev_g.py` — archive-only generator for the superseded four-outlet record

The human handoff summary is `docs/fabrication-handoff-index.md`.

Raw material procurement estimate:
- `data/manual/fabrication_metal_stock_requirements.csv`
- `data/manual/fabrication_raw_material_estimates.csv`
- `docs/fabrication-metal-stock-list-20260514.md`
- `docs/fabrication-raw-materials-procurement-estimate-20260513.md`

The raw-stock estimate adds procurement rows for mild-steel battery/radiator sheet, plate, pre-formed 90-degree angle/L-section stock, aluminium and plastic electrical plate stock, small EPDM isolator sheet, and separate tub repair steel sheets/plates. Chassis-rubber materials remain controlled by the chassis-rubber/body-mount procurement rows rather than this Fabrication workstream.

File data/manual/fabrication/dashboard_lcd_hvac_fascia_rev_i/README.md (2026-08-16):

# J40 RHD factory-height 9-inch LCD dashboard — Rev I

Status: **owner-corrected V44 factory-height centre-section design incorporating the purchased Pioneer DMH-AP6650BT. The visibly closed new panel starts beside the glovebox, replaces the ashtray, central opening and lower slot completely, and finishes at the speedometer-side boundary. Its two rounded upper corners echo the retained OEM openings, and its bottom is the untouched factory lower dashboard edge with 0 mm downward extension. Quotation, full-size transparent-template and full-depth rear-buck release only; production metal and vehicle cutting remain HOLD pending the complete M1/M2 trace, actual components and rear-buck proof.**

Current appearance direction: [V44 factory-height rounded-corner proposal](dashboard_rev_i_v44_factory_height_rounded_top_corners_proposal.md), with the accepted [body-colour front-on design](dashboard_rev_i_v44_factory_height_rounded_top_corners.png) and [boundary/mounting diagram](dashboard_rev_i_v44_factory_height_rounded_top_corners_boundary.svg). These are deliberately **non-dimensional**: do not scale their pixels or trace them for CNC work. V44 is a closed, balanced panel between the retained glovebox and speedometer. Both upper corners use smooth OEM-style radii and the bottom is the unchanged factory dashboard edge with 0 mm drop. It consumes the ashtray, central rectangular opening and lower slot while keeping the Pioneer face flush. M2 must establish every perimeter edge and radius directly in the vehicle. V43's sharp upper transitions and the earlier V41/V42 boundary studies are superseded; V40 remains a historical oblique design-intent reference. Signed M1–M9 evidence and actual components control fabrication geometry; M10 is the post-fit electrical/functional commissioning gate. Rendered lettering is not an engraving master.

Current dimensional-control package: [V46-D1 A1 1:1 PDF](dashboard_rev_i_v46_d1_component_package_1to1.pdf), [editable 1:1 SVG](dashboard_rev_i_v46_d1_component_package_1to1.svg), [component dimension schedule](dashboard_rev_i_v46_d1_component_dimension_schedule.csv) and [measurement-control specification](dashboard_rev_i_v46_d1_measurement_control_spec.md). V46-D1 establishes the manufacturer-published receiver and selector envelopes at physical size and identifies every unresolved M1–M9 measurement. It does not change V44's appearance direction and is marked **NOT FOR CUTTING** because the dashboard perimeter, component apertures, mounting points and rear service envelopes still require the vehicle and received parts.

## Purchased receiver baseline — 2026-08-16

- **Selected and purchased:** [Pioneer DMH-AP6650BT](https://pioneer-mea.com/en/products/dmh-ap6650bt/) 9-inch multimedia receiver from [DMC Dragon](https://dmcdragon.com/pioneer-dmh-ap6650bt-9in-screen-apple-carplay/). Purchase price, transaction/payment state, delivery and physical receipt were not supplied, so the unit is recorded as ordered/pending delivery rather than on hand.
- **Known depth input:** published main-chassis dimensions are approximately **188 W × 108 H × 37 D mm**. The 37 mm body is nominally 43 mm shallower than the existing ≤80 mm chassis target and leaves 78 mm inside the 115 mm quotation envelope before carrier, fasteners, fully mated connectors, cable bends, service loops, ventilation allowance and removal sweep.
- **Geometry boundary:** the published front/nose is approximately **229 W × 131 H × 13 D mm** and the main chassis approximately **188 W × 108 H × 37 D mm**. Neither figure establishes the exact corner radii, visible opening, complete installed projection or connector/bend envelope. The V37 **232 × 134 mm** face aperture is a mock-up provision for approximately 1.5 mm reveal only. M4/M5 physical measurement and M9 buck proof still control every production cut and mount.
- **Navigation:** navigation is projected from a connected phone through Apple CarPlay or Android Auto; this is not a standalone Android-navigation tablet.
- **Audio baseline:** commission the receiver first on its built-in **22 W RMS × 4 at 4 Ω** amplifier. Its **4 V front/rear/subwoofer RCA pre-outs** support a later compact external amplifier; reserve a serviceable RCA/remote-turn-on/power route without committing the dash cassette to an amplifier location.

Project photograph `photos/20260317_165113.jpg` controls the intact factory cluster identity and its installed relationship to the column/shroud. `photos/20260413_040719.jpg` controls the straight-on aperture, normal lower edge and deep factory U/scallop and is the structural reference for the [V44 design](dashboard_rev_i_v44_factory_height_rounded_top_corners_proposal.md). The owner-supplied marked photograph controls the concept: the large asymmetric silver-grey door is the retained OEM glovebox, while a closed centre section beginning at its right-hand line—including the smaller silver ashtray, central black opening and lower slot—is replaced only as far as the distinct speedometer-side seam. The signed M1/M2/M3 physical trace overrides every rendering, AI-generated seam and pixel.

V44 is the current front-on appearance/perimeter direction. It supports the factory-height silhouette, zero drop, rounded OEM-style upper corners and a visibly closed, balanced centre-section replacement derived from the owner's corrections, but the rendering is not registered to an exact vehicle trace. V43 and the earlier V41/V42 studies are superseded boundary studies; V40 remains a historical oblique design-intent reference. The charcoal/alternate renders are rejected, V39 is superseded, and no image or earlier V35 file closes M1/M2 or proves production cut geometry.

The geometry-controlled V25 check maps the selected layout onto the old photograph in two perspective regions meeting on the fixed factory steering axis. This keeps the photographed top edge, both ends, normal lower edge and column/scallop position as the target datums instead of stretching the old dashboard to the concept. Use the [transparent alignment overlay](dashboard_rev_i_v25_exact_height_column_overlay.png) to audit the registration and the [mapped layout](dashboard_rev_i_v25_exact_height_column_mapped.png) to review the resulting arrangement. The yellow line is the retained steering-axis datum and the cyan outline is the photographed fascia boundary. V25 remains image-registration evidence, not a substitute for M1/M3 physical tracing.

V26–V32, the free-standing V38 studies and the narrower [V39 centre-insert interpretation](dashboard_rev_i_v39_glovebox_line_insert_proposal.md) are superseded visual development. [V40](dashboard_rev_i_v40_full_ashtray_section_proposal.md) established the broad replacement intent, [V41](dashboard_rev_i_v41_front_on_full_section_proposal.md) transferred it to the front-on photograph, V42 tested the glovebox-to-speedometer limit, and V43 established the balanced closed-panel direction. [V44](dashboard_rev_i_v44_factory_height_rounded_top_corners_proposal.md) is active: the removable replacement has rounded OEM-style upper corners, consumes all three old centre features, retains the factory lower edge and never continues to the far-right dash end. The earlier V35 registered files remain historical quotation aids only; they do not control V44 production coordinates.

## CNC handoff routes

The package intentionally exposes two different routes in the project portal so a quotation model cannot be mistaken for a production release:

1. **Exact production-CNC route:** complete the field work in the [measurement and survey checklist](cnc_measurement_and_survey_checklist.md), enter each result and evidence reference in the [fillable measurement schedule](cnc_measurement_schedule.csv), then replace every `ASSUMED` and `TRACE-LOCK` item before issuing the production DXF.
2. **Measurement/component route now:** use the [V46-D1 1:1 component sheet](dashboard_rev_i_v46_d1_component_package_1to1.pdf) and [dimension schedule](dashboard_rev_i_v46_d1_component_dimension_schedule.csv) to verify the purchased package against the field trace. Print at actual size and verify the 100 × 100 mm calibration square before comparison. This is not a panel-cut file.
3. **Quotation/prototype route now:** use the [V44 proposal](dashboard_rev_i_v44_factory_height_rounded_top_corners_proposal.md) and [boundary/mounting diagram](dashboard_rev_i_v44_factory_height_rounded_top_corners_boundary.svg) to quote only a full-size clear/card/MDF perimeter template, a hidden backing-frame prototype and a full-depth rear buck. V35 may inform historical scale and component discussions, but its centre-cassette perimeter and coordinates must not be quoted as the V44 replacement section.

The quotation route uses a clearly marked 1400 × 250 mm plotting envelope, the provisional display-face figures plus the published Pioneer main-chassis dimensions, provisional V35 cassette/outlet/control coordinates and direct-trace placeholders for the glovebox, cluster and column. It is sufficiently defined for costing and prototype planning, but it is deliberately incomplete for production cutting. The [2026-08-02 rear-clearance photo audit](rear_clearance_photo_audit_20260802.md), [machine-readable photo evidence](rear_clearance_photo_evidence_20260802.csv), [rear-package control diagram](rear_package_clearance_control.svg), [outlet addendum](ac_outlet_87mm_cnc_addendum.md), [outlet interface schedule](ac_outlet_interface_schedule.csv) and [switch allocation schedule](switch_position_schedule.csv) remain part of both routes.

## Locked visible arrangement

- Replace the complete dashboard skin section beginning at the glovebox's right-hand line and continuing rightward to the signed M2 termination. Its top and bottom follow the owner's marked existing dashboard lines. The original ashtray pressing and adjacent rectangular opening both disappear inside this one removable, flush CNC-formed section. Do not use a rounded plaque, floating screen bezel or smaller cassette inside those openings. Preserve the OEM glovebox, speedometer/cluster, RHD column/scallop, cowl, windscreen frame, A-pillars and all structure outside the signed boundary.
- The insert extension/drop is **0 mm**: its lower boundary terminates at the existing full-width lower dashboard line. Any future extension needs owner approval after the physical survey and must never alter the lower edge, glovebox, cluster, column scallop or either end contour.
- Transfer the original large asymmetric glovebox and original Toyota speedometer assembly without changing their identity, size, construction or installed position. Keep the speedometer on its directly traced factory column axis immediately above the original shroud/scallop. Preserve the glovebox's exact directly traced rounded outline and position, silver-grey finish, black Japanese plate, upper black knob, seams, hinges and latch, and preserve the cluster's exact finish, colour, patina, markings, glass and needles. Do not move either OEM assembly for visual balance or clearance. The M2 trace must prove where the replacement terminates before reaching the retained cluster/column structure.
- Centre the purchased Pioneer DMH-AP6650BT 9-inch receiver in the signed free field of the V44 replacement section, not on an assumed full-fascia midpoint. Keep its front exactly coplanar with the new skin and raise it enough to retain the single control line below. The published front/nose is approximately **229 × 131 × 13 mm** and the V37 trial aperture is **232 × 134 mm**; both are mock-up inputs only. The published main chassis is approximately **188 × 108 × 37 mm**. For quotation and the rigid buck only, cap the complete installed rear projection at **115 mm** and retain the ≤80 mm chassis/body target. The purchased unit, controlled drawing if available, perpendicular M5 depth map and actual-part buck control the production aperture, reveal, mounts, connectors, cable bend, service loop, ventilation and removal path.
- Use exactly **two** matching large circular chrome/silver directional A/C outlets, each centred in a retained measured outer clear land. The owner-supplied target family is Ø87 mm at the visible face, Ø75 mm at the rear mounting interface and no more than approximately 22 mm from the finished rear fascia plane to the louver body. Their final centres are set only after the physical fascia trace, component measurement and complete rear-envelope buck. Retain the other two as matched service spares. There are no centre or lower outlets and no vent dips.
- Retain the purchased MOMO-style three-spoke wheel, original RHD column position and directly traced factory column scallop.
- Treat the signed factory column opening/scallop X and Y as immutable. Align the installed shaft, boss and wheel hub concentrically to that opening; never move or reshape the opening merely to suit the rendered wheel or cluster artwork.

- Use exactly **seven** bought black long-lever selectors plus one separate red hazard in one compact line below the LCD on the V44 replacement section: `WIPERS | LIGHTS | SPOTS | AUX | BLOWER | A/C | FUEL STOP | HAZARD`.

  `WIPERS`, `LIGHTS` and `BLOWER` are 3-position. `SPOTS`, `AUX`, `A/C` and `FUEL STOP` are 2-position. `FUEL STOP` is a low-current RUN/STOP request only; key OFF remains authoritative and the original manual stop cable remains the mechanical fallback.

## Selector inventory and allocation

- Received inventory is four 2-position selectors and three 3-position long-handle selectors. All seven are allocated: the 2-position units serve `SPOTS`, `AUX`, `A/C` and `FUEL STOP`; the 3-position units serve `WIPERS`, `LIGHTS` and `BLOWER`. No selector remains spare and no additional selector is required.
- Bought from Purchaser: [Schneider 2-position selector](https://purchaser.com.pk/schneider-harmony-22mm-push-button-2-position-selector-switch-black-maintained-1-no-600-v/) and [Schneider XB4 3-position long-handle selector](https://purchaser.com.pk/schneider-selector-switch-harmony-xb4-metal-black-22mm-long-handle-3positions-stay-put-2no/). The [owner's photograph](bought_long_handle_selector_reference.png) controls the visible form: round chrome bezel, black circular face and long black lever, with the square mounting/contact body concealed behind the fascia. The actual received samples and fitted contact blocks control M6.
- The visible `BLOWER` states are `OFF / LOW / HIGH`. The donor unit's medium-speed tap remains unused unless a separately documented and bench-proven controller redesign is later approved; it does not create a requirement for a four-position fascia selector.
- Every visible selector carries only a low-current relay/controller request. No blower-motor, lamp, compressor-clutch or fuel-solenoid load is routed directly through the fascia selector.

## Outlet order and inventory control

- Daraz order `246057471480938`, confirmed and paid on 2026-08-02, contains two line items of the selected `2 Grills` variant from AL.Zain Mart: **four physical circular vents ordered, zero received**. The paid total is PKR 4,569 and the stated delivery window is 2026-08-05 through 2026-08-08. [Purchased product listing](https://www.daraz.pk/products/suzuki-cultus-dashboard-ac-grill-side-grill-2018-2024-chrome-suzuki-cultus-2017-2024-avk-dashboard-ac-grill-vent-chrome-1-grill-pc-suzu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).
- The listing supports the Suzuki Cultus/Celerio 2017–2024 application and chrome-finish appearance only. It does not prove that the surround is solid metal, and it publishes no trustworthy face, cutout, barrel, spigot or rear-depth dimensions. Describe the finish as **chrome/silver** until receipt inspection establishes the substrate and construction.
- The `Ø87 / Ø75 / 22 mm` supplied-reference image and V31/V32 renders remain a provisional visual-family study, not a drawing of this purchased SKU. No fascia aperture, centre coordinate, retainer or duct adapter may be released from those values.
- At receipt, photograph and label all four, reject cracked plating or damaged vanes, record the full M7 measurement set, choose the closest-matching pair for the vehicle and bag the remaining two together as service spares.

## Factory speedometer and column alignment

The existing installed dashboard establishes the alignment rule:

1. In a perpendicular front view, the centre of the main speedometer dial, the centre of the column/shroud at the fascia plane and the steering-wheel hub lie on the same directly traced vehicle axis.
2. Transfer the complete cluster, aperture and mounts as one rigid datum at the exact position measured on the installed vehicle. Do not move it upward or downward to create artificial clearance or visual balance.
3. The cluster lower lip sits immediately above the installed steering-column shroud, with only the directly traced narrow body-colour seam. The aperture approaches the normal lower edge closely; only the compact upward-opening factory scallop wraps the column below it. Do not leave the broad cream band or large circular collar shown in rejected studies.
4. The column, shroud, stalks, boss and wheel are installed before the M3/M9 trace. The signed swept envelope, not a nominal coordinate, controls the relief.
5. V35 is a proportional front-face study only. It does not establish or alter the aperture coordinate; M3 must transfer the cluster, opening, shaft, shroud and wheel axis directly from the assembled vehicle.

## Dimensional confidence

| Item | Current dimensional basis | Release status |
| --- | --- | --- |
| Pioneer DMH-AP6650BT display, main chassis and rear package | Purchased 2026-08-16. Official operation manual publishes a 229 × 131 × 13 mm front/nose, 188 × 108 × 37 mm chassis and 196.608 × 114.15 mm effective display area. V46-D1 draws these envelopes at 1:1. The old 211.10 × 126.50 mm face and 198.91 × 111.89 mm active-image placeholders are superseded. Photo-audit quotation cap: 115 mm total installed projection; retained chassis/body target: ≤80 mm | Published envelopes do not prove corner radii, screen offset within the nose, mounts, connector/cable envelope or complete installed projection. Received-unit calipers, perpendicular M4/M5 depth map and actual M9 buck must lock the complete installed/service envelope |
| MOMO wheel | Vendor listing: nominal Ø350 mm and about 90 mm depth | Actual wheel, boss/adapter, installed dish and column position HOLD for M3 |
| Industrial selectors | Four Schneider XB4BD21 controls with official 30 W × 47 H × 68 D mm envelope and three XB4BJ33 controls with official 30 W × 48 H × 68 D mm envelope; both families publish nominal Ø22.5 mm mounting diameter. V46-D1 draws the envelopes at 1:1 | Actual parts, cutout details, anti-rotation features, lever sweep, complete rear stack, labels, contacts and terminals HOLD for M6 coupon proof |
| Circular outlets | Four ordered 2026-08-02 as two Daraz `2 Grills` packs; owner-supplied target family is Ø87 visible face / Ø75 rear mounting interface / ≤ approximately 22 mm rear louver-body depth | Ordered 4 / received 0. Targets control V35 and the fit coupon only; exact visible OD, cutout/barrel, retention, spigot, shutoff, aim range, rear package and material remain HOLD for M7 |
| OEM cluster, large glovebox and column relief | Owner vehicle itself | Direct trace only; no image or public catalogue dimension may replace M1–M3 |
| Complete fascia perimeter and height | Owner vehicle itself | No production dimension yet. The public 1400 × 250 × 100 mm replacement-panel listing is only a vendor envelope, not this RHD vehicle's cut geometry |

The visual proportions are therefore suitable for design selection and quotation, but **not yet dimensionally accurate enough for production CNC**. Public listings confirm the general panel envelope; they do not establish this vehicle's lower edge, folds, cluster/glovebox apertures, column scallop or behind-dash depth.

For the M1–M3 trace, keep the directly traced glovebox and speedometer coordinates unchanged; do not force them onto a common datum or move them to balance the new parts. Define `(X_LCD, Y_LCD)` from the measured free centre field within the removable cassette, not from the midpoint of the complete fascia. The centre of the bought LCD's measured active image—provisionally **198.91 × 111.89 mm**—not merely its bezel or chassis, must coincide with that signed cassette datum. Maintain at least 10 mm of verified fixed-metal/service clearance around the complete installed/service LCD package and adjacent retained parts.

## 2026-08-02 rear-clearance photo audit

The Google Photos Picker imported three rear-dashboard measurement photographs. Two oblique local rays read approximately **125–130 mm** and **160–170 mm**. The third shows a **270–280 mm endpoint reading, not a measured span**, because its tape zero/start is outside the frame. The endpoints are not fully declared and none is registered to the finished rear-fascia plane, the complete LCD envelope or either planned outer vent centre. They are therefore useful obstruction/context evidence only.

- **Vent body:** the nominal approximately 22 mm louver-body projection is not contradicted by the smallest apparent span. This is a provisional body-only check, not proof of a complete outlet installation.
- **Complete vent assembly:** **NOT PROVEN / HOLD M7 and M9**. The photos omit the retainer, spigot or adapter, clamp, hose OD, first bend, duct support, moving louver envelope and removal path, and they do not show either actual vent site.
- **LCD quotation maximum:** use `P_LCD_INSTALLED,Q ≤ 115 mm` measured perpendicular from the finished rear fascia to the furthest part of the complete installed/service package. The Pioneer main chassis is published at approximately 37 mm depth, nominally within the retained `P_LCD_CHASSIS ≤ 80 mm` target and leaving 78 mm of quotation-envelope budget. That remainder is not verified clearance: it must absorb the carrier/mounts, fasteners, largest fully mated connector, cable bend/service loop, ventilation allowance and removal tolerance.
- **LCD production maximum:** not yet released. Calculate `P_LCD_INSTALLED,PROD ≤ min[Z_FIXED(x,y)] − 10 mm` over the complete installed and removal envelope, with at least 20 mm to the moving column/shroud/stalk envelope. The smaller clearance result controls.

See the [photo audit](rear_clearance_photo_audit_20260802.md), [evidence schedule](rear_clearance_photo_evidence_20260802.csv) and [control diagram](rear_package_clearance_control.svg). The 115 mm cap is deliberately conservative. M5 measurements may replace that quotation number; production release still requires the complete actual-part M9 rear-buck validation.

## A/C outlet target interface control

Keep the outlet interfaces separate in every drawing, quote and inspection record:

| Interface | Target used by V35 | Production instruction |
| --- | ---: | --- |
| Visible front face, `D_FACE` | Ø87.0 mm | Appearance/proportion envelope; radius 43.5 mm |
| Rear mounting boss or barrel, `D_MOUNT_MAX` | Ø75.0 mm target maximum | Measure every received part at several clock and axial positions; this is not yet a production aperture |
| Louver-body projection, `P_BODY` | ≤ approximately 22 mm | Measure from the finished rear fascia plane to the end of the louver body; record retainer, spigot, clamp and first bend separately |
| Production panel aperture, `D_CUT` | Not released | Define from the measured retention system and a successful same-material, same-thickness, final-finish coupon |
| Hose spigot/adapter, `D_SPIGOT` | Unknown | Measure OD, ID, projection, bead and usable hose engagement; Ø75 mounting data must never be used as a hose size |

If—and only if—the received outlet is a slip-through, back-retained design and its measured maximum boss diameter is no greater than 75.00 mm, the first coupon may use `D_CUT = Ø75.50 mm +0.25 / −0.00`. A snap, interference, threaded or clip-retained design instead uses the retention manufacturer's requirement or a physically proven coupon size. The coupon must be made in the same 1.5 mm CR4 sheet, with the same edge preparation, primer and final paint build as the production fascia.

At the provisional LCD active-image size, each Ø87 face is **43.74% of active width** and **77.76% of active height**. Those ratios control only the V35 front-view visualization; CAD coordinates come from the signed vehicle trace and received-part measurements.

## Available-space audit

| Zone | Photograph-supported conclusion | Remaining physical proof |
| --- | --- | --- |
| Central LCD / former ashtray | The central face field is the least obstructed visible zone and a 9-inch active image is proportionally credible without lowering the dashboard. The imported photos support only a conservative 115 mm quotation cap for the complete installed package; they do not establish a production depth | Measure perpendicular `Z_FIXED` over the actual LCD chassis, carrier, connector/bend and removal envelope. Confirm `P_LCD_INSTALLED ≤ Z_FIXED − 10 mm` throughout and prove the complete package in the buck |
| OEM cluster and steering column | The original cluster already occupies almost the full factory-height band and must stay directly over the column | Trace the aperture, column scallop, shroud/stalk sweep, support bracket and cluster rear body with the vehicle assembled |
| Passenger outer outlet / glovebox | V35 places the Ø87 target face in the retained passenger outer clear land outside the unchanged glovebox lid. The imported tape photographs do not identify this centre and cannot prove its rear space | At the marked actual centre, map perpendicular depth over the full complete outlet/duct swept envelope. Prove ≥10 mm to fixed glovebox box, hardware and full opening/removal sweep; otherwise revise the outlet/duct hardware without moving the glovebox or crushing the duct |
| Driver outer outlet / cluster/column | V35 places the Ø87 target face in the retained driver outer clear land. The imported tape photographs do not identify this centre and cannot prove its rear space | At the marked actual centre, prove the complete outlet/duct package clears cluster, body return, control rear stacks and looms by ≥10 mm and the moving column/shroud/stalk envelope by ≥20 mm. Preserve service access; revise outlet/duct hardware rather than move OEM parts or lower the fascia |
| Two-takeoff evaporator | The photographs show usable open under-dash volume once the old hang-on unit is removed, but the driver side is occupied by the column, cluster and loom | Record the selected case's complete W × H × D, fittings, drain fall, return-air face, brackets and removal path; construct a rigid full-depth mock-up with both end branches |
| Normal fascia height | V44 follows the owner's marked original lower dashboard line with 0 mm downward extension | Capture a perpendicular full-size trace at five or more stations; the vehicle trace, not the rendered edge, controls the replacement section |

The two outer outlets solve the screen interference seen in the central-vent studies, but they require longer branches. Accept the compact two-takeoff evaporator only after both complete end runs are fitted and tested together; do not assume that a small case or two decorative louvers proves usable duct takeoffs.

## Mandatory clearances and routing

- At least 20 mm from every new fixed part, duct and wire to the signed moving column/shroud/stalk envelope through full movement.
- At least 10 mm between vent retainers, necks, elbows or ducts and fixed LCD, cluster, glovebox hardware, selector contact stacks, terminals, loom and structural hardware.
- Where the Ø87 visible face and a 10 mm visible gap control, keep an outlet centre at least **53.5 mm** from a glovebox-lid edge, unsupported fascia boundary or adjacent visible component. Where only a conditional Ø75.5 mm trial aperture and 10 mm structural land control, keep the centre at least **47.75 mm** from that boundary; the stricter 53.5 mm face rule controls wherever both apply.
- Keep each outer outlet wholly on fixed fascia. The passenger outlet and rear package must remain outside the complete glovebox opening sweep.
- Support both duct branches. No duct section may be crushed below 90% of its round inside diameter; use the largest practical bend radius and prove balanced useful airflow at both ends.
- Preserve an original or dedicated windscreen-demist path; the two occupant outlets are not the sole demist provision.
- Preserve cabin-side service removal for the LCD, both vents, the control bank and evaporator connections.

## Measurement and release sequence

| Gate | Required evidence before production release |
| --- | --- |
| M1 — fascia | Perpendicular 1:1 physical trace/scan of top fold, both ends, normal lower edge at ≥5 stations, body returns, attachment structure, existing centre opening and true free centre field; record the cassette/LCD datum without altering the retained fascia |
| M2 — glovebox / full centre-section boundary | Direct trace of the large asymmetric glovebox lid perimeter and opening, hinges/latch, upper black knob, black instruction plate, rear depth and full opening sweep; then trace the V44 top joint, both tangent upper radii, left seam beside the glovebox, unchanged lower edge and right seam at the speedometer side. Balance the visible panel without moving either OEM opening. Record the ashtray, central opening and lower slot as removed features inside the replacement, not as retained apertures |
| M3 — cluster/column | Cluster aperture and rear package; installed column axis/angle; factory scallop; boss, shroud, stalk and wheel swept envelopes |
| M4/M5 — Pioneer receiver | On physical receipt, measure the DMH-AP6650BT display/bezel outline, active image and offsets, corner radii, mount pattern and interfaces; confirm the published approximately 188 × 108 × 37 mm main chassis and replace the provisional 211.10 × 126.50 mm face and 198.91 × 111.89 mm active-image figures. Record a perpendicular actual-location `Z_FIXED` depth map and the complete installed/service projection including chassis, carrier, fasteners, heat sink, fully mated connectors, cable bends/service loops, ventilation and removal path; replace the 115 mm quotation cap before production release |
| M6 — controls | All seven bought selectors plus the separate hazard: cutouts, anti-rotation, head/lever sweeps, complete rear-stack depths, contact truth tables, terminals and harness exits |
| M7 — outlets | Receive, label and measure all four ordered vents at multiple clock and axial positions: visible face OD, boss/barrel maximum and minimum OD plus ovality, retention and anti-rotation, body depth from the finished rear fascia plane, retainer projection, spigot OD/ID/projection/engagement/bead, shutoff, aim range, finish/material, hose/clamp fit and cabin-side service path. At both marked actual centres, record a perpendicular depth map over the complete retention/duct swept envelope and compare it with the assembled total projection. Prove the selected aperture in a same-thickness, final-finish coupon; choose the best-matched pair for installation and label/store the other two as matched spares |
| M8 — HVAC | Selected two-takeoff evaporator W × H × D plus fittings, drain, intake, blower, mounts and two complete supported duct branches |
| M9 — rear buck | Rigid full-depth rear buck with every retained/bought component installed; glovebox, column/stalk, knees and every lever exercised. Prove the actual LCD projection against its M5 depth map and both complete vent/duct assemblies against their M7 site maps, simultaneously |
| M10 — electrical/functional | Selector truth tables, relay/controller interfaces, wiper park, lighting, blower speeds, A/C safety/fan logic, hazard isolation, FUEL STOP RUN/STOP, key-off and manual-stop fallback |

## CNC quotation and first-article instruction

- Quote in two stages: (1) inexpensive full-size clear/card/MDF replacement-section template, hidden backing-frame prototype and rear buck; (2) production V44 replacement section only after M1–M9 approval.
- Production intent: one removable, flush 1.2–1.5 mm formed-steel V44 replacement section with matching rounded upper transitions, radiused/deburred edges, a continuous hidden backing/Z-frame and concealed serviceable attachment. It begins beside the glovebox, closes at the speedometer-side seam and replaces the complete centre skin between them without extending below the factory lower line. Body colour is the selected first prototype finish. Hidden M5 fasteners may be proposed at no more than 150 mm pitch where retained structure permits.
- Use the signed vehicle trace and bought-component drawings as CAD masters. Do not scale the V44 rendering, V35 PNG/elevation, any earlier render or the historical Rev H DXF/CSV.
- Quote an outlet fit coupon for each distinct retention geometry before production cutting. The coupon aperture is governed by M7 measurements and retention proof, not by the nominal Ø75 target alone.
- Unless a bought-component drawing requires tighter control, quotation targets are ±0.5 mm for flat cut-feature position, ±0.25 mm for cut-feature size and ±2 mm for the cassette perimeter against the signed checking template. Supplier must state achievable tolerances before acceptance.
- The normal lower edge must match the signed original-height trace. Only the directly traced factory steering-column scallop may interrupt it.
- Do not cut the vehicle or production metal until the disposable template fits, the full-depth mock-up passes and the owner/body shop sign the M1–M9 release sheet.

## Current verdict

**Visual/front-face package: PASS for the V44 owner-directed factory-height, rounded-corner centre-section replacement concept only.**

**Closed and balanced glovebox-side/speedometer-side cut direction; matching rounded upper transitions; complete removal of the ashtray, central opening and lower slot; zero-drop flush screen and one-line selector/hazard allocation: PASS visually in V44. Physical traces, actual components and a complete rear buck remain mandatory.**

**Behind-dash package: CONDITIONAL. The approximately 22 mm vent body is provisionally plausible in the imported local-cavity photos, but neither complete outlet/duct assembly is proven at its actual centre. The Pioneer receiver's published approximately 37 mm main chassis is within the ≤80 mm target, but its complete installed projection may use 115 mm only for quotation/buck and production depth remains HOLD until M5/M9. No clash is proven until M3/M5/M6/M7/M8/M9.**
**Production CNC or vehicle-cut release: HOLD.**

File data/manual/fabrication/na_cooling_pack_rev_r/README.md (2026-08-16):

# Naturally aspirated cooling-pack visual references — Rev R

These two photorealistic images deliberately show two mutually exclusive states:

- `rev_r_ph01_original_parts_split_out.png` — exactly five original components, all off the vehicle and separated.
- `rev_r_ph02_fully_installed_in_vehicle.png` — the complete pack fixed in its final vehicle position, with no loose or exploded parts.

The images are arrangement and identity aids. The tagged original parts, direct measurement sheets, signed fabrication drawings and physical dry fit remain controlling.

## Generation mode

Built-in OpenAI ImageGen with the repository source photographs supplied as image references.

## Exact prompt — PH01 split-out

> Create one size-faithful, photorealistic workshop reference photograph for a Toyota J40 cooling-pack restoration guide.
>
> Use case and style: documentary workshop photography, neutral colour, natural soft overhead light, high-detail metal and fin textures, 3:2 landscape frame, straight-on to slightly elevated camera, no typography and no diagram styling.
>
> The five reference images identify the exact five original components and their geometry. Reproduce those same physical parts, not generic modern replacements:
> 1. The aged copper/brass radiator with its near-square narrow core, dark top tank, central-near filler neck and cap, lower mounting legs and original side structure. Finished overall radiator envelope is approximately 635 mm wide and approximately 610 mm body height (approximately 635 mm to cap).
> 2. The near-square aluminium A/C condenser with the exact fin-panel proportions and vertical receiver/drier cylinder along its side, approximately 540 mm wide by 465 mm high.
> 3. The exact original black expanded-mesh stone guard, including its long top rail, asymmetrical outline, noticeably curved/irregular right perimeter and the real mounting tabs. Do not make it rectangular.
> 4. The exact large rear puller fan: circular fan/ring about 450–480 mm across held by the simple open rectangular perimeter frame seen in the source. Open corners; no modern full-width moulded shroud.
> 5. The exact small front pusher fan: one standalone circular caged fan about 240–255 mm across, with its original compact mounting ears/frame. Exactly one small fan.
>
> Composition: all five components are completely OFF THE VEHICLE and separated from one another by generous clear space, arranged as a clean, simple parts-layout photograph on a neutral grey workshop floor. Each component is upright/front-face visible and shown at a consistent scale so the radiator is visibly larger than the condenser and the small fan is visibly much smaller than the large fan. Show exactly these five major components, no car, no engine bay, no assembled stack, no extra duplicate fans, no hoses, no fabricated brackets, no captions, no arrows, no dimension text, no stands obscuring the shapes.
>
> Condition: professionally restored but not redesigned—clean straight fins, repaired original frames, satin black guard and fan frames, honest period-correct copper/brass radiator details. Preserve every distinctive asymmetry and mounting feature from the references.

## Exact prompt — PH02 installed

> Create one photorealistic final-installation photograph for a Toyota J40 cooling-pack restoration guide.
>
> Use case and style: credible documentary workshop photography, neutral colour, natural soft daylight, sharp real metal/paint/fin textures, 3:2 landscape frame, slightly elevated front three-quarter camera. This must read immediately as a completed installation in a real vehicle—not an exploded view, mock-up, dry fit, transitional state or parts display. No typography, callouts, arrows or dimension text.
>
> Vehicle and state: a complete, period-correct Toyota J40 in a clean workshop, bonnet open. The front grille insert/service-facing trim may be removed only to give the camera a clear view, but the body front apron, wings and cooling pack are installed. Every cooling component is fixed in its final plane with realistic bolts and brackets. The stone guard must be upright, tight against its installed support position and visibly bolted—never lowered, tipped forward, leaning, held by a person, resting on the floor or separated from the vehicle. No loose parts anywhere.
>
> Preserve the exact component identities shown in the references:
> - the original period copper/brass radiator, approximately 635 mm wide by 610 mm body height, with the same dark top tank, filler neck/cap and original side and lower mounts;
> - one aluminium A/C condenser approximately 540 by 465 mm, with a vertical receiver/drier at its side;
> - the exact original satin-black expanded-mesh stone guard with its long top rail, asymmetrical outline, distinctly curved/irregular right perimeter and real tabs; do not turn it into a rectangular aftermarket grille;
> - one large rear puller fan, circular ring approximately 450–480 mm, in the simple open rectangular perimeter frame seen in its reference, mounted behind the radiator on the engine side; no modern moulded full-width shroud;
> - exactly one small front pusher fan, circular ring approximately 240–255 mm, using the compact cage and mounting ears from its reference.
>
> Final installed layer order from front toward the engine: body/grille opening, stone guard, exactly one small front pusher fan, condenser, radiator, one large rear puller fan, engine. The pack should be compact and aligned, with plausible narrow service gaps and no exploded spacing. From this front three-quarter viewpoint the fixed guard and small fan should be clearly visible; show glimpses of the condenser/radiator behind the mesh and the engine bay beyond, while keeping every layer physically joined to the vehicle.
>
> Do not add a second small fan. Do not show any part beside or in front of the car. Do not duplicate the pack. Do not create a split-screen, inset, collage or cutaway. Do not show a chassis-only vehicle.

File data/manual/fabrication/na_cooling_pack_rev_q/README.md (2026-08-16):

# NA cooling-pack photorealistic reference views — Rev Q

These generated images are reference-constrained visualisations. They communicate only two unambiguous states: every component separated off the vehicle, or the complete pack assembled in the vehicle. They are not dimensional evidence, cut drawings, or substitutes for the controlled photographs and direct measurements in Rev P.

## PH01 — split out off vehicle

File: `rev_q_ph01_split_out_off_vehicle.png`

Built-in ImageGen prompt:

> Create a high-resolution photorealistic exploded workshop photograph, landscape 3:2, of the complete Toyota J40 cooling and A/C pack split out OFF THE VEHICLE. No car, chassis, engine, body panels, wheels or grille may appear anywhere.
>
> Arrange the parts upright on simple neutral workshop stands in a clear left-to-right front-to-rear sequence with generous equal separation between every layer: irregular stone guard; exactly one small circular front pusher fan; full-face condenser; square copper/brass radiator; exactly one large puller fan in its full rectangular shroud. Include the fabricated lower crossmember, rubber saddles and small independent mounting carriers separately below the relevant parts. Nothing is assembled together, overlapping, floating or touching.
>
> IDENTITY LOCK: preserve the exact component forms established by the references. Guard has long upper bar, expanded mesh and curved irregular right perimeter. Condenser has left vertical receiver-drier and right-side pipework/manifold. Radiator has black top tank, central filler cap, hose neck, projecting side ears and lower tank. One small fan only. Large fan remains inside its broad original rectangular shroud.
>
> PROPORTION LOCK: radiator about 635 x 635 mm; condenser body about 540 x 465 mm; large fan ring about 450–480 mm; small fan about 240–255 mm. Make their relative sizes visually consistent. Restored but believable used condition. Clean Pakistani fabrication workshop, eye-level three-quarter view, soft daylight, realistic materials and shadows. No text, no arrows, no labels, no people, no logos.

## PH02 — assembled in vehicle

File: `rev_q_ph02_assembled_in_vehicle.png`

Built-in ImageGen prompt:

> Create one high-resolution photorealistic documentary workshop photograph, landscape 3:2, of the completed cooling and A/C installation on a restored Toyota J40. View from directly in front and slightly above with the bonnet open and grille/front service panel removed so the finished stack and its mounting details are visible. Retain the same naturally aspirated 2H chassis/engine context and exact components established in the supplied restored-parts and dry-fit images.
>
> IDENTITY LOCK: the foremost removable stone guard must keep the supplied original's irregular expanded-mesh shape, long upper bar, asymmetrical mounting holes and curved right-hand perimeter. Visible directly behind it is exactly one small circular pusher fan matching the supplied fan. Behind that is the same full-face condenser with its left receiver-drier and bent right-side pipework, then the same square copper/brass radiator with black top tank, central filler cap, upper hose neck, projecting side ears and lower tank. The large puller remains behind the radiator inside its full rectangular shroud. No intercooler, no turbo, no second front fan, no twin-fan module, no generic modern aluminium radiator.
>
> PROPORTION LOCK: radiator visual envelope about 635 x 635 mm; condenser body about 540 x 465 mm centered inside it; large fan ring about 450–480 mm; one small fan ring about 240–255 mm. Keep those relative sizes and leave believable 20–30 mm service gaps through the stack.
>
> FINAL STATE: fabricated crossmember and short connector arms are satin black, radiator sits in two black rubber lower saddles with neutral upper keepers, each guard/condenser/fan carrier is independently bolted and removable, wiring is in black split conduit with two sealed relay/fuse enclosures mounted on the inner wing away from heat. Clean professional restoration but not showroom-perfect; subtle wear, realistic fasteners and workshop dust. Natural daylight in a Pakistani restoration shop. No people, no text, no labels, no arrows, no logos, no transparent/x-ray parts.

## Excluded view

The earlier mixed dry-fit/on-car view is deliberately excluded from the page and deliverable because it combines assembled and split-out states.

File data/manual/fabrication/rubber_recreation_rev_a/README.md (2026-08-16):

# J40 Rubber Recreation Fabrication Pack - Rev A

This is the fabrication-output package for the body-mount and front-support rubber recreation workstream.

Use it with:

- `docs/rubber-recreation-fabrication-spec-20260502.md`
- `data/manual/rubber_recreation_fabrication_specs.csv`
- `data/manual/rubber_recreation_measurement_closure.csv`
- `data/manual/rubber_recreation_manufacturing_requirements.csv`

## Files To Send

- `j40_rubber_recreation_rev_a_dimension_sheet.pdf` - dimension and fabrication review sheet
- `machine_definitions.csv` / `machine_definitions.json` - CNC/shop geometry, shim-pack controls, and controlled non-CNC purchase definitions
- `fabricator_cut_list.csv` - file-by-file cut/form list
- `inspection_checklist.csv` - receiving and first-article inspection checks
- `chassis_rubber_current_order_preview_rev_a.svg` - current Longman order preview; active quote/first-article lines only
- `models_3d/` - parametric OpenSCAD 3D models and old-part closure questions

## DXF / SVG Parts

- `bm_iso_sm_square_pad_rev_a.dxf` / `bm_iso_sm_square_pad_rev_a.svg` - BM-ISO-SM small-height square body isolator pad, qty 10 plus 6 spares
- `bm_iso_lg_square_pad_rev_a.dxf` / `bm_iso_lg_square_pad_rev_a.svg` - BM-ISO-LG large square body isolator pad, qty 2 plus 2 spares
- `bm_cup_small_seat_washer_rev_a.dxf` / `bm_cup_small_seat_washer_rev_a.svg` - BM-CUP small body-mount cup washer, qty 10 working basis
- `bm_cup_large_seat_washer_rev_a.dxf` / `bm_cup_large_seat_washer_rev_a.svg` - BM-CUP large body-mount cup washer, qty 2 working basis
- `fs_oval_front_support_pad_rev_a.dxf` / `fs_oval_front_support_pad_rev_a.svg` - FS-OVAL front support two-hole isolator pad, qty 2 matched pieces
- `fs_strip_left_template_blank_rev_a.dxf` / `fs_strip_left_template_blank_rev_a.svg` - FS-STRIP-L underfloor body-support strip first-article blank, qty 1
- `fs_strip_right_template_blank_rev_a.dxf` / `fs_strip_right_template_blank_rev_a.svg` - FS-STRIP-R underfloor body-support strip first-article blank, qty 1
- `exh_hgr_90917_08004_teardrop_rev_a.dxf` / `exh_hgr_90917_08004_teardrop_rev_a.svg` - EXH-HGR-90917 teardrop exhaust cushion, qty as fitted

## Layer Rules

- `CUT`, `CUT_BORE`, `CUT_RELIEF`, and `DRILL` are through-cut or through-hole geometry.
- `RECESS`, `FORM`, and `INSERT_MARK` are register, forming, boss, or pocket controls. Do not through-cut them unless the physical sample proves that construction.
- `TEMPLATE` is a trace/quote guide only when present. The current strip rubbers are released as plain `CUT` blanks.
- `CENTER` is construction geometry only.

## Release Limits

The square BM-ISO body pads, cup blanks, and oval pad are ready for quote and first article from these files. Full production still requires the hold dimensions in `data/manual/rubber_recreation_measurement_closure.csv`.

The current Longman rubber-order basis for the main body pads is square flat isolator pads, not the earlier circular placeholder. Use `bm_iso_sm_square_pad_rev_a.dxf` / `.svg`, `bm_iso_lg_square_pad_rev_a.dxf` / `.svg`, and the matching `models_3d/bm_iso_sm_square_pad.scad` / `models_3d/bm_iso_lg_square_pad.scad` files for the current envelope. They default to an `18.0 mm` bore, matching the Toyota `90560-12009` style body-mount sleeve basis. Production release uses the 18.0 mm bore; `hole_d = 0` is a non-release CAD override only. The old circular `BM-SM` / `BM-LG` drawings are legacy placeholders and are not active Longman body-pad controls.

The shim packs are controlled in `machine_definitions.csv` / `machine_definitions.json` as new flat steel thickness packs. They are not released as fixed DXF outlines until the original shim or mount-station footprint is traced in millimeters; do not substitute washer stacks.

The strip files are released plain first-article cut patterns at `420 x 38 x 8 mm`. The May 17 ruler photos show about `16.5 in` old-strip length, converted to `419 mm` and rounded to `420 mm`. Do not add holes, slots, bonding, raised-load pads, or handed trim unless the dry-fit and physical retainer prove them; trace/reuse the steel retainer separately if it must be remade.

The exhaust holder is controlled as a teardrop cushion style using Toyota `90917-08004` / `17572-92000` only as a reference shape. Source exact new molded stock if it is in hand; otherwise the CAD file is a local-copy control and needs a genuine sample or intact original before a production mould is cut.

Bump stops cannot rely on Toyota/manufacturer supply. Public OEM/catalog sources checked confirm the Toyota numbers, application, and `70 mm`/`60 mm` height split, but not the Toyota mould drawing, compound recipe, or load/deflection curve. Use `docs/bump-stop-fabrication-spec-20260504.md`: long `48304-60010` positions are `70 mm` free height and the right-front `48304-60020` is `60 mm`. The usable May 31 photos give nearest-`5 mm` provisional readings of `~70 mm` long-sample height, `~110 mm` metal-fixture length, `~65 mm` rubber-body span along the mounting-hole axis, and `~90 mm` metal mounting-hole pitch. They also show the broad molded rubber body on a metal backing/fixture with exposed mounting ears, central fixture/channel interface, rounded/tapered sides, and flat strike area. These values control identification and first-fit screening only; direct caliper/thread-gauge/vehicle measurements still release BW/D/thread/fixture-channel/X-Y/G/F. Photo `20260531_171833` is unrelated and excluded. Do not make bump stops from simple cut rubber blocks or the earlier flat-plate placeholder.

## Material

Use new black automotive mount-grade solid rubber only: EPDM or NR/SBR, Shore A `60 +/-5`, for body/front-support rubbers. Bump stops use the separate higher-duty target in the bump-stop spec: NR/SBR automotive bump-stop rubber Shore A `70 +/-5`, or cast PU Shore A `80 +/-5` only if the May 31 metal-backed mounting layout, central fixture/channel interface, progressive geometry, and rebound recovery are proven. Reject tyre rubber, crumb rubber, sponge foam, mixed offcuts, used rubber, salvage rubber, and unmarked compound.

Steel cups must be `2.5-3.0 mm` steel, deburred and zinc plated or epoxy primed after forming. Sleeves are still controlled by stack dry-fit and are not released as a cut DXF.

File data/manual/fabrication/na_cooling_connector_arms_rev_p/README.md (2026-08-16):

# Naturally Aspirated Cooling Connector Arms + Holders — Rev P

This is the controlled fabrication handoff for the naturally aspirated cooling-pack mount. It records the owner's 15 August 2026 correction that the two radiator arms are **loose parts and are not attached to the chassis**. They may therefore be shortened or replaced on the bench and made directly to the real chassis connector interfaces.

Rev P supersedes Rev O. It retains Rev O's shortened connector arms and holder scope while replacing the former chained centring rule with direct vehicle-centreline control. Rev O already superseded the Rev N X2-adapter arrangement and the nominal 410 mm / 4 mm dimensions in `front_radiator_two_side_retention_rev_a`; none of those older values may be used for final cutting, drilling or material purchase.

## Controlled visual and drawing basis

The five actual retained-component photographs for R0, C0, G0, FS and FL control component identity, surface condition and the interfaces that must be measured. Former AI workshop renders have been withdrawn from the controlled portal because their component forms did not match the originals. Never recreate a tab, rail, pipe, shroud, guard perimeter or mounting feature from an illustration.

Four functional fabrication sheets cover every fabricated reference in this handoff:

- `rev_p_d01_lower_support_and_connector_arms.svg` — X0, X1-L/R, A0-L/R and A1-L/R.
- `rev_p_d02_guard_and_radiator_holders.svg` — G1-L/R, G2-L/R, R0-E, R3-U-L/R and optional R3-L-L/R.
- `rev_p_d03_heat_exchanger_and_fan_carriers.svg` — C1, F1 and F2, including the controlled one-FS stack order.
- `rev_p_d04_electrical_and_release_matrix.svg` — E1, the two independent fan branches and the release evidence for all 13 fabricated-reference groups.

These are interface, load-path, assembly and release-control drawings—not cut-ready manufacturing drawings. Every unreleased section, thickness, cut length, bend, hole centre, weld, fastener and torque is marked or governed as **HOLD** until the named direct-measurement record and signed competent-person drawing exist.

## Controlled load path

`R0 → R1 lower saddles → X1 seats → X0 crossmember → shortened A0-L/A0-R arms with A1 connector ends → verified chassis connectors`

R3-U locates only. Optional R3-L stabilises only. G1/G2 carry only the G0 perimeter frame. C1, F1 and F2 are independent carriers. No tank, solder seam, fin pack, mesh or heat-exchanger core may carry mounting load.

## Critical sizing rule

Each A0 arm starts at the actual A0-D connector bearing plane and stops at the highest released functional bracket/interface. No unused tall projection remains. Final height is a datum-derived drawing value, never a photograph-scaled or inherited nominal dimension.

The actual loose arm blanks may be reworked only after identity, material, thickness/section, straightness, corrosion, old holes, cracking and heat damage are accepted. If they cannot satisfy the released connector, edge-distance and load requirements, fabricate a new matched pair from certified weldable structural steel.

## Central alignment rule

`CL0` is a fixed-datum centre record, not a visual judgement. Project the vehicle longitudinal centre plane (`VCL`) at the G0, FS and C0 mounting planes. Hold the complete repaired G0 perimeter-frame outer-envelope centre, complete mounted FS frame/rotor datum and C0 usable-fin-field lateral centreline each within `±2 mm` laterally of VCL. Separately, hold G0 within `±2 mm X/Z` of the measured usable fixed vehicle-grille aperture centre and FS within `±2 mm X/Z` of the C0 usable-fin-field centre. The fixed vehicle grille/body opening is not G0; G0 is the removable expanded-mesh stone guard. Represent all frames, tabs, guards, plugs, cable bends and service envelopes, but do not substitute those clearance envelopes for the perimeter-frame or frame/rotor centring datums. Measure every direct VCL offset independently: no tolerance stacking. If the complete assemblies cannot satisfy both the direct and local limits, revise G1/G2, C1 or F1 before release; do not approve an offset by eye.

## Photo-backed mock-up baseline

The controlled tape photographs now pre-populate the first full-size fixture: R0 body height is approximately `610 mm`, R0 cap/highest point is approximately `635 mm`, and the C0 body is approximately `540 × 465 mm`. These three readings are **LOCKED FOR MOCK-UP**, not final fabrication dimensions. The photographed R0 horizontal span of approximately `635 mm`, FL ring of approximately `450–480 mm`, and FS ring/frame of approximately `240–255 mm` / up to about `280 mm` are **PROVISIONAL**. Depths, holes, lower-saddle centres, connectors, brackets and vehicle fit remain **HOLD**. The signed square direct measurements in `measurement_basis.csv` supersede any photo reading for final fabrication.

## Holder scope

- `G1-L/R`: lower rubber-faced grille/stone-guard cradles for the sound G0 perimeter frame.
- `G2-L/R`: removable upper/side grille/stone-guard keepers with positive accessible retention.
- `R0-E`: radiator-shop repair/reproduction of released sound radiator-side ears or tabs.
- `R3-U-L/R`: short sleeved-EPDM upper radiator keepers; locator/restraint only.
- `R3-L-L/R`: optional lower-side stabilisers; no vertical load and no copy of the historical added leg.
- `F2`: independent rear fan/shroud carrier and seal land; no tank/core load.

## Handoff sequence

1. Load the photo-backed mock-up baselines already recorded in `measurement_basis.csv`, then replace/complete the final records from square direct measurement of the actual chassis connectors, guard, R0 radiator and retained components.
2. Make rigid A0-D-L/R, B0, S0, CL0, G0-H and R0-H templates from fixed vehicle datums, projecting VCL directly at the G0, FS and C0 planes.
3. Inspect the two loose arm blanks and record retain/rework/replace decisions.
4. Produce a competent-person structural calculation and drawing for X0/X1/A0/A1, connector bearing, welds, fasteners, torque and proof fixture.
5. Bench-cut/jig the shortened mirror-handed A0 assemblies; never trim an installed structural member.
6. Design G1/G2 from G0-H/CL0 and R3/R0-E from R0-H. Design F1 from CL0 and the complete FS/C0 maps. G1/G2 and F1 must each satisfy their direct VCL limit as well as their local aperture/C0 limit. Every holder must have an assigned load/function and service path.
7. Complete an opaque bare-metal 1:1 dry fit with actual rubbers, hardware, hoses, wiring and service tools.
8. After structural release, apply a **total** static proof load of `2 × MR`, distributed between the two S0 saddle centres in the released loaded-radiator distribution, for 10 minutes without local point-loading.
9. Complete `inspection_checklist.csv`, coat, assemble and commission under the Rev P guide.

## Files

- `fabricator_cut_list.csv` — complete make/buy mounting schedule; all final dimensions held.
- `measurement_basis.csv` — mandatory measurement and template record.
- `inspection_checklist.csv` — fabrication, proof, finish and installation gates.
- `rev_p_d01_lower_support_and_connector_arms.svg` — controlled lower-support and connector-arm drawing.
- `rev_p_d02_guard_and_radiator_holders.svg` — controlled guard and radiator-holder drawing.
- `rev_p_d03_heat_exchanger_and_fan_carriers.svg` — controlled condenser and fan-carrier drawing.
- `rev_p_d04_electrical_and_release_matrix.svg` — controlled electrical drawing and fabrication release matrix.

The controlling narrative is `docs/J40-naturally-aspirated-cooling-pack-restoration-guide-rev-p-20260816.md`.

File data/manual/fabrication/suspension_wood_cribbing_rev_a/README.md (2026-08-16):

# J40 Suspension Wood Cribbing Pack - Rev A

This is the controlled cut package for the hardwood support blocks and wedge chocks needed before the Ironman suspension and brake work window.

Status: fabrication completed and closed on 2026-08-16. Retain this Rev A package as the reference for the received set.

## Send To Scout / Timber Merchant

- `j40_suspension_wood_cribbing_rev_a_dimension_sheet.pdf`
- `suspension_wood_cribbing_rev_a_3d_visualisation.html`
- `suspension_wood_cribbing_rev_a_3d_visualisation.svg`
- `fabricator_cut_list.csv`
- `inspection_checklist.csv`

Plain request:

> I need 8 seasoned solid hardwood blocks, finished 300 x 150 x 75 mm, plus 4 solid hardwood wedge chocks, finished 200 x 100 mm base with 75 mm rear height and 25 mm nose height. Use dry dense hardwood such as sheesham/shisham, kikar/acacia, oak, ash, or equivalent. Raw unfinished wood, flat faces, no plywood/MDF/softwood/wet/cracked/painted pieces.

## Send To Fabricator / Workshop

- Use the same PDF as the control drawing.
- Use `swc_wedge_chock_rev_a.dxf` if the workshop will cut the wedge taper from rectangular blanks.
- Use the SVG files as quick visual references.

## Parts

| ID | Qty | Finished size |
| --- | ---: | --- |
| SWC-BLOCK-001 | 8 | 300 L x 150 W x 75 H mm |
| SWC-CHOCK-001 | 4 | 200 L x 100 W base, 75 mm rear height, 25 mm nose height |

If the timber merchant cannot cut the wedge taper cleanly, buy 4 extra 200 x 100 x 75 mm hardwood blanks and have the workshop cut them to `SWC-CHOCK-001`.

## Safety Position

These blocks are supplemental cribbing and chocks for a controlled suspension/brake work setup. They are not a substitute for rated jack stands, a rated trolley jack, or proper axle support.

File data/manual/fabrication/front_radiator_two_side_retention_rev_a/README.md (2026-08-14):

# J40 Front Radiator Two-Side Retention Pack - Rev A

> **SUPERSEDED — DO NOT FABRICATE.** The owner's 15 August 2026 physical-state correction confirms the radiator arms are loose and not attached. The 410 mm height, 4 mm material and 618 mm developed template below are historical only. Rev O now controls: measure the actual chassis connector interfaces, then shorten/rework or replace the loose arms to end at the highest required functional attachment. See `../na_cooling_connector_arms_rev_o/README.md`.

This package now uses a single 4 mm mild-steel formed-angle radiator post with a chassis-straddling saddle at the bottom. The existing-side radiator bracket measurements are imported; the remaining hold is right-side transfer and dry-fit, not the basic bracket dimensions.

## Design Intent

- Replace the wire-held or one-sided radiator support condition with a simple bolt-through formed-angle post: upright leg, full-depth top screw tab, chassis bridge, and two chassis-side saddle legs.
- Avoid welding to the chassis as the default route. The two lower legs straddle the chassis/front-support section and are retained by a through-bolt.
- Preserve the radiator plane and fan clearance unless a dry-fit proves a correction is needed.
- Use rubber washers/bushes at the radiator screw as required, but do not fabricate a separate large rubber pad for this bracket unless the vehicle dry-fit proves it is needed.
- Use crush-tube/spacer practice if the through-bolt passes through boxed chassis/front-support metal.
- If the bought aluminium radiator does not land on this bracket, add only a removable rubber-isolated adapter between the vehicle-side bracket and the radiator mounting ear/rail. Do not add a hard extra leg to the aluminium tank/core.

## Part In This Package

1. `front_radiator_saddle_right_angle_post_rev_a` - 4 mm mild-steel formed angle section using the measured `48 mm` main face and `410 mm` upright height. The developed template length is now `618 mm`: `58 mm` top return, `410 mm` upright, `70 mm` chassis bridge, and `80 mm` far-side leg. The upright lower continuation is the near-side saddle leg.

## Existing-Side Measurement Basis

- Existing-side measurement photos are the basis for the main-face template and bends.
- Measured main face width: `48 mm`; the released 3D view now shows the perpendicular return flange so the post reads as a formed angle section rather than a flat strap.
- Upright/post height: `410 mm`; this is the height basis visible in the in-vehicle tape-measure photo, not the whole developed length.
- Developed main-face template length: `618 mm`.
- Top screw return: `58 mm`.
- Chassis bridge allowance: `70 mm`; verify this against the right-side chassis/front-support width before cutting final steel.
- Outer saddle leg: `80 mm`.
- Measurement basis rows are in `measurement_basis.csv`.

## 3D Visualisation

- `front_radiator_two_side_retention_rev_a_3d_visualisation.svg` is the static fabrication-read view.
- `front_radiator_two_side_retention_rev_a_3d_visualisation.html` is the interactive fabrication-read view.
- `front_radiator_two_side_retention_rev_a_assembled_3d_visualisation.svg` is the static attached assembly view.
- `front_radiator_two_side_retention_rev_a_assembled_3d_visualisation.html` is the interactive attached assembly view with the formed-angle return flange, full-depth top return, clean near/far saddle legs, through-bolt, and top screw shown together.

## Right-Side Holds Before Final Metal

- Transfer the existing-side top screw location to the right side and verify the radiator ear lands without pulling the radiator out of plane.
- Confirm right-side chassis/front-support width, cleaned metal condition, through-bolt route, and whether a crush tube/spacer is needed.
- Rubber washer/bush stack at the top screw.
- Fan-to-radiator clearance after the bracket is tightened.
- Hose sweep, bonnet closure, radiator service removal, and coating access.
- For an aluminium radiator, adapter/cradle need is decided only after dry-fit. Any adapter must be removable, rubber-isolated, and must not load the tank/core.

## Fabrication Rules

- Use `4.0 mm` mild steel for the released template.
- Prefer pre-formed 90-degree mild-steel angle/L-section stock if one leg is close to `48-50 mm`; otherwise form a perpendicular return flange from flat stock before final transverse bends. Mitre/relieve the bend points as needed so the angle section can form the top return and lower saddle cleanly.
- Bend the top return to match the left-side bracket direction and offset; the top return should continue back to the far edge of the formed angle section rather than stopping at the upright face.
- Bend the lower saddle around the actual chassis/front-support width so the near-side and far-side saddle legs sit down both chassis sides without added side ears or tabs.
- Through-bolt both saddle legs and chassis/front support; do not weld this bracket unless the bolted saddle route fails dry-fit.
- The top slot is a transfer aid from the existing-side bracket. Open the final screw hole after the right-side radiator ear and washer/bush stack are dry-fit.
- Deburr all edges, radius the top tab corners, and protect every cut edge before final assembly.

## Release State

This is ready for cardboard/flat-bar dry-fit and fabricator discussion using the imported existing-side dimensions. It does not release blind drilling of the final right-side holes until the dry-fit proves the transfer.

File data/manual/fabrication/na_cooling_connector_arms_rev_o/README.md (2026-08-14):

# Naturally Aspirated Cooling Connector Arms + Holders — Rev O

This is the controlled fabrication handoff for the naturally aspirated cooling-pack mount. It records the owner's 15 August 2026 correction that the two radiator arms are **loose parts and are not attached to the chassis**. They may therefore be shortened or replaced on the bench and made directly to the real chassis connector interfaces.

Rev O supersedes the Rev N X2-adapter arrangement and the nominal 410 mm / 4 mm dimensions in `front_radiator_two_side_retention_rev_a`. Those older values must not be used for final cutting, drilling or material purchase.

## Controlled load path

`R0 → R1 lower saddles → X1 seats → X0 crossmember → shortened A0-L/A0-R arms with A1 connector ends → verified chassis connectors`

R3-U locates only. Optional R3-L stabilises only. G1/G2 carry only the G0 perimeter frame. C1, F1 and F2 are independent carriers. No tank, solder seam, fin pack, mesh or heat-exchanger core may carry mounting load.

## Critical sizing rule

Each A0 arm starts at the actual A0-D connector bearing plane and stops at the highest released functional bracket/interface. No unused tall projection remains. Final height is a datum-derived drawing value, never a photograph-scaled or inherited nominal dimension.

The actual loose arm blanks may be reworked only after identity, material, thickness/section, straightness, corrosion, old holes, cracking and heat damage are accepted. If they cannot satisfy the released connector, edge-distance and load requirements, fabricate a new matched pair from certified weldable structural steel.

## Central alignment rule

`CL0` is a fixed-datum centre record, not a visual judgement. Hold the repaired G0 perimeter centre within 2 mm of the usable grille-aperture centre in both axes. Hold the C0 usable-fin-field lateral centreline within 2 mm of the vehicle longitudinal centre plane. Hold the FS motor/rotor axis within 2 mm of the C0 usable-fin-field centre laterally and vertically. The complete guard and complete fan frame, tabs, guard, plug, cable bend and service envelope must fit at those coordinates. If they do not, revise the carriers before release; do not approve an offset by eye.

## Holder scope

- `G1-L/R`: lower rubber-faced grille/stone-guard cradles for the sound G0 perimeter frame.
- `G2-L/R`: removable upper/side grille/stone-guard keepers with positive accessible retention.
- `R0-E`: radiator-shop repair/reproduction of released sound radiator-side ears or tabs.
- `R3-U-L/R`: short sleeved-EPDM upper radiator keepers; locator/restraint only.
- `R3-L-L/R`: optional lower-side stabilisers; no vertical load and no copy of the historical added leg.
- `F2`: independent rear fan/shroud carrier and seal land; no tank/core load.

## Handoff sequence

1. Complete `measurement_basis.csv` from the actual chassis connectors, guard, R0 radiator and retained components.
2. Make rigid A0-D-L/R, B0, S0, CL0, G0-H and R0-H templates from fixed vehicle datums.
3. Inspect the two loose arm blanks and record retain/rework/replace decisions.
4. Produce a competent-person structural calculation and drawing for X0/X1/A0/A1, connector bearing, welds, fasteners, torque and proof fixture.
5. Bench-cut/jig the shortened mirror-handed A0 assemblies; never trim an installed structural member.
6. Design G1/G2 from G0-H/CL0 and R3/R0-E from R0-H. Design F1 from CL0 and the complete FS/C0 maps. Every holder must have an assigned load/function and service path.
7. Complete an opaque bare-metal 1:1 dry fit with actual rubbers, hardware, hoses, wiring and service tools.
8. After structural release, apply a **total** static proof load of `2 × MR`, distributed between the two S0 saddle centres in the released loaded-radiator distribution, for 10 minutes without local point-loading.
9. Complete `inspection_checklist.csv`, coat, assemble and commission under the Rev O guide.

## Files

- `fabricator_cut_list.csv` — complete make/buy mounting schedule; all final dimensions held.
- `measurement_basis.csv` — mandatory measurement and template record.
- `inspection_checklist.csv` — fabrication, proof, finish and installation gates.

The controlling narrative is `docs/J40-naturally-aspirated-cooling-pack-restoration-guide-rev-o-20260815.md`.

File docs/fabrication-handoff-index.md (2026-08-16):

# Fabrication Handoff Index

Purpose: one send-out index for the ready-to-run non-rubber fabrication packages in this repository.

All package dimensions are in `mm`. For each package, send the package PDF for human review plus the listed `DXF` files for cutting. Keep the matching `SVG` files with the job if the shop wants a quick visual reference.

Dashboard UI: open the `Fabrication` workstream in `docs/project-control-ui/` for clickable package links, status gates, and first-article steps.

Raw material procurement: use [fabrication-raw-materials-procurement-estimate-20260513.md](fabrication-raw-materials-procurement-estimate-20260513.md), [fabrication-metal-stock-list-20260514.md](fabrication-metal-stock-list-20260514.md), and `data/manual/fabrication_raw_material_estimates.csv`. Existing `3.0 mm` and `4.0 mm` stock asks cover the named battery/EPS work only. Rev P radiator-arm and holder stock is a do-not-buy HOLD until A0-D/CL0/G0-H/R0-H templates and the signed structural drawing release exact material, section, thickness, length and quantity.

## Chassis Rubber Boundary

Chassis/body rubber order control is not owned here. Use [chassis-rubbers-workstream.md](chassis-rubbers-workstream.md) and [longman-rubber-order-spec-20260508.md](longman-rubber-order-spec-20260508.md) for body-mount pads, front-support isolators, bump stops, sleeves, shims, cup washers, and related Longman/first-article release holds.

The old rubber package files remain in the repository as supporting reference material, but the active Fabrication workstream should not send or close chassis-rubber orders independently. The current Longman package lives at [data/manual/fabrication/longman_rubber_order_20260508](../data/manual/fabrication/longman_rubber_order_20260508/README.md), with an interactive 3D visualisation and a package zip generated through the dashboard. The current square-pad 3D quote models live in [data/manual/fabrication/rubber_recreation_rev_a/models_3d](../data/manual/fabrication/rubber_recreation_rev_a/models_3d/README.md); use those rather than the older circular body-pad placeholders when discussing the May 8 Longman rubber order.

## Dashboard 9-inch LCD / HVAC Fascia - Rev I (active design hold)

Current specification and packaging gate: [data/manual/fabrication/dashboard_lcd_hvac_fascia_rev_i](../data/manual/fabrication/dashboard_lcd_hvac_fascia_rev_i/README.md)

Current dimensional-control package: [V46-D1 A1 1:1 component PDF](../data/manual/fabrication/dashboard_lcd_hvac_fascia_rev_i/dashboard_rev_i_v46_d1_component_package_1to1.pdf), [editable 1:1 SVG](../data/manual/fabrication/dashboard_lcd_hvac_fascia_rev_i/dashboard_rev_i_v46_d1_component_package_1to1.svg), [dimension schedule](../data/manual/fabrication/dashboard_lcd_hvac_fascia_rev_i/dashboard_rev_i_v46_d1_component_dimension_schedule.csv) and [measurement-control specification](../data/manual/fabrication/dashboard_lcd_hvac_fascia_rev_i/dashboard_rev_i_v46_d1_measurement_control_spec.md). This sheet draws only manufacturer-published component envelopes at physical size. It is **NOT FOR CUTTING** and does not infer the centre-panel perimeter from photographs.

Current appearance direction: [V44 factory-height rounded-corner proposal](../data/manual/fabrication/dashboard_lcd_hvac_fascia_rev_i/dashboard_rev_i_v44_factory_height_rounded_top_corners_proposal.md), with the accepted [body-colour front-on design](../data/manual/fabrication/dashboard_lcd_hvac_fascia_rev_i/dashboard_rev_i_v44_factory_height_rounded_top_corners.png) and [boundary/mounting diagram](../data/manual/fabrication/dashboard_lcd_hvac_fascia_rev_i/dashboard_rev_i_v44_factory_height_rounded_top_corners_boundary.svg). They are non-dimensional and must not be scaled or traced. V43's sharp-corner study and V41/V42 are superseded boundary studies; V40 remains a historical oblique design-intent reference. Only a new M1/M2 vehicle trace can define the V44 production geometry.

V44 keeps the OEM glovebox and speedometer unchanged and forms one visibly closed, balanced centre panel between them. Its two upper corners use smooth OEM-style radii matching the neighbouring openings, its side seams close at those OEM boundaries, and its bottom remains the factory lower line with 0 mm drop. The panel consumes the ashtray, central rectangular opening and lower slot without continuing to the far-right dashboard end. It holds the purchased Pioneer DMH-AP6650BT flush, plus one line of seven bought black long-lever selectors and a separate red HAZARD. All perimeter coordinates, radii, component apertures and rear packaging remain HOLD pending physical traces, actual components and a rigid full-depth rear buck.

Portal/CNC handoff: use the [measurement and survey checklist](../data/manual/fabrication/dashboard_lcd_hvac_fascia_rev_i/cnc_measurement_and_survey_checklist.md) and [fillable M1–M10 schedule](../data/manual/fabrication/dashboard_lcd_hvac_fascia_rev_i/cnc_measurement_schedule.csv). M1–M9 release the measured fabrication geometry and physical fit; M10 closes post-fit electrical/functional commissioning before vehicle handoff. Use V46-D1 to compare component packages and record the missing data, not as a panel outline. The V44 rendering and every earlier image/elevation/specification are prototype inputs only and must not be used to cut the vehicle or production fascia.

## Dashboard 9-inch LCD / HVAC Fascia - Rev G (superseded four-outlet record)

Directory: [data/manual/fabrication/dashboard_lcd_hvac_fascia_rev_g](../data/manual/fabrication/dashboard_lcd_hvac_fascia_rev_g/README.md)

Send-out archive: `deliverables/fabrication_packages/dashboard_lcd_hvac_fascia_rev_g.zip`

Primary files:
- `j40_dashboard_lcd_hvac_fascia_rev_g_shop_spec.pdf`
- `dashboard_lcd_hvac_fascia_rev_g_dimensioned_front.svg`
- `dashboard_lcd_hvac_fascia_rev_g_photo_overlay_bare_shell.png`
- `dashboard_lcd_hvac_fascia_rev_g_photo_overlay_assembled.png`
- `fabricator_cut_and_release_schedule.csv`
- `measurement_and_release_schedule.csv`
- `switch_position_schedule.csv`
- `dimensional_provenance_audit.csv`

DXF files:
- `full_width_fit_template_rev_g.dxf` - nominal `1260 x 280 mm` full-face coordinate/template envelope with three local vent drops; M1 physical trace controls the final perimeter
- `full_width_fascia_master_rev_g.dxf` - same one-piece architecture with every metal/component feature retained on named HOLD layers
- `lcd_rear_support_reference_rev_g.dxf` - nominal rear-support/reference geometry; actual LCD chassis and mount drawing control

Rev G superseded Rev A-F, but is itself superseded by Rev I above. It replaced the complete visible face, deleted the ashtray, transferred the original glovebox and speedometer assemblies, locked a mathematically true 9-inch active-image reference, integrated four same-height vents, and consolidated all controls at the far right. Retain it for design history only; do not send its four-outlet coordinates as the current dashboard job.

Release position:
- Ready for CNC quotation, full-size vehicle trace/scan, 1:1 plot and disposable prototype only.
- Do not cut production vehicle metal or final LCD/selector/hazard/vent apertures until M1-M9 are closed against the actual vehicle and bought parts, rear screen/contact blocks and duct bends clear, and the owner signs the physical 1:1 layout. Close M10 after installation as the electrical/HVAC functional commissioning gate before vehicle handoff.
- The nominal fascia centreline is `X=630.0`. LCD active image, bezel and aperture share it exactly. Inner vent centres are `X=555.0` and `705.0`, so their midpoint is exactly `X=630.0`; all four vent centres share `Y=50.0`.
- Exactly seven selectors are shown: top Wipers, Lights, Spots, Aux; bottom Blower, A/C, Engine; the separate red Hazard occupies the eighth bank position and is not counted among the seven.
- Functions matched the purchased four 2-position plus three 3-position inventory. The historical `ENGINE` label is now named `FUEL STOP` in Rev I and remains an EEI-003 electrical release HOLD with key OFF authoritative and manual cable retained; A/C remains subject to thermostat/pressure/trinary interlocks. T1/T2 remain low/high beam and the original dip control remains in service.
- Screen mass is carried by rear supports tied into the dashboard structure, not the `1.5 mm` visible fascia alone. Electrical selectors command relays/controller inputs rather than carrying accessory loads directly.

## Battery Stand Power Carrier - Rev A

Directory: [data/manual/fabrication/battery_power_carrier_mount_rev_a](../data/manual/fabrication/battery_power_carrier_mount_rev_a/README.md)

Control spec: [front-engine-bay-mounting-fabrication-plan-20260508.md](front-engine-bay-mounting-fabrication-plan-20260508.md)

Primary files:
- `data/manual/fabrication/battery_power_carrier_mount_rev_a/j40_battery_power_carrier_mount_rev_a_dimension_sheet.pdf`
- `data/manual/fabrication/battery_power_carrier_mount_rev_a/battery_power_carrier_mount_rev_a_assembled_3d_visualisation.html`
- `data/manual/fabrication/battery_power_carrier_mount_rev_a/battery_power_carrier_mount_rev_a_assembled_3d_visualisation.svg`
- `data/manual/fabrication/battery_power_carrier_mount_rev_a/battery_power_carrier_mount_rev_a_3d_visualisation.html`
- `data/manual/fabrication/battery_power_carrier_mount_rev_a/battery_power_carrier_mount_rev_a_3d_visualisation.svg`
- `data/manual/fabrication/battery_power_carrier_mount_rev_a/fabricator_cut_list.csv`
- `data/manual/fabrication/battery_power_carrier_mount_rev_a/inspection_checklist.csv`
- `data/manual/fabrication/battery_power_carrier_mount_rev_a/component_layout.csv`

DXF files:
- `battery_stand_compact_top_tray_rev_b.dxf` - steel compact `340 x 265 mm` battery tray/deck for the installed Daewoo DLS120 datum from the May 17 ruler photos, with the previous `318 x 180 x 230 mm` envelope kept only as comparison, qty `1`
- `battery_stand_compact_single_chassis_pickup_rev_b.dxf` - formed chassis saddle over rail, qty `1`
- `battery_stand_adjustable_offset_bar_rev_b.dxf` - slotted `360 x 60 x 4 mm` body-side offset bar from the formed chassis saddle/upright bridge toward the battery pocket, qty `2 mirrored`
- `battery_stand_compact_single_mount_upright_rev_b.dxf` - upright bridge side plate, qty `2 mirrored`
- `battery_stand_compact_hold_down_crossbar_rev_b.dxf` - service-removable `340 x 38 mm` battery hold-down crossbar, qty `1`
- `battery_power_compact_front_service_rail_rev_b.dxf` - **superseded/hold**; do not fabricate this former `660 x 310 mm` relay/MIDI battery-stand ladder under the 2026-07-31 layout decision
- `battery_power_compact_cutoff_tab_rev_b.dxf` - folded 100A breaker/cutoff base/guard, qty `1`

Release position:
- 2026-07-31 supersession: retain this package only for the battery tray, chassis saddle/support, hold-down, and battery-side cutoff/breaker. Relay Rev D and MIDI Rev D move to a removable plate on the structural radiator/cooling-stack carrier.
- Rev F standard-battery access update is a prototype/mock-up release for the steel chassis-mounted battery stand.
- The stand must mount from the one known formed chassis saddle, upright bridge, and slotted body-side offset bars, not the battery tray skin, radiator support strap, or unsupported inner wing.
- It supports the installed Daewoo DLS120 battery datum captured in the May 17 ruler photos on a removable hold-down tray and retains the 100A breaker/cutoff close to the battery.
- The tray/front ladder starts around `190 mm` wing-side/outboard from the more central chassis pickup, with the offset bars retaining `160-230 mm` adjustment until dry-fit locks the setting.
- Battery positive must enter the battery-side cutoff/breaker first. Its protected output runs to the structural cooling-stack electrical plate, where it feeds MIDI fuse 4 and the relay battery-side entry without changing circuit assignments or fuse sizing.
- Final drilling still needs the battery/cutoff mock-up plus a separate radiator-carrier electrical mock-up proving airflow, fan/shroud, hose, cap, drain, bonnet, grille, heat/splash, relay-cover, MIDI-lid, cable-bend, disconnect, and radiator-removal clearances.

## Naturally Aspirated Cooling Connector Arms and Holders - Rev P

Directory: [data/manual/fabrication/na_cooling_connector_arms_rev_p](../data/manual/fabrication/na_cooling_connector_arms_rev_p/README.md)

Control spec: [J40-naturally-aspirated-cooling-pack-restoration-guide-rev-p-20260816.md](J40-naturally-aspirated-cooling-pack-restoration-guide-rev-p-20260816.md)

Primary files:
- `data/manual/fabrication/na_cooling_connector_arms_rev_p/README.md`
- `data/manual/fabrication/na_cooling_connector_arms_rev_p/measurement_basis.csv`
- `data/manual/fabrication/na_cooling_connector_arms_rev_p/fabricator_cut_list.csv`
- `data/manual/fabrication/na_cooling_connector_arms_rev_p/inspection_checklist.csv`

Release position:
- Current naturally aspirated handoff with exactly one FS front A/C pusher plus one FL rear radiator puller.
- A0/A1 arm dimensions and stock remain HOLD until the actual connector templates and competent-person structural drawing are signed.
- The fixed vehicle grille/body opening is distinct from removable G0. CL0 requires the complete repaired G0 perimeter-frame centre, complete FS frame/rotor datum and C0 usable-fin-field lateral centreline to each meet VCL directly within `±2 mm` laterally. Separately, G0-to-usable-fixed-aperture and FS-to-C0 X/Z checks are `±2 mm`; do not tolerance-stack.
- G1/G2 guard holders and R0-E/R3 radiator holders remain separate from the radiator weight path and heat-exchanger cores.

## Front Radiator Two-Side Retention - Rev A (superseded historical package)

Directory: [data/manual/fabrication/front_radiator_two_side_retention_rev_a](../data/manual/fabrication/front_radiator_two_side_retention_rev_a/README.md)

Control spec: [front-engine-bay-mounting-fabrication-plan-20260508.md](front-engine-bay-mounting-fabrication-plan-20260508.md)

Primary files:
- `data/manual/fabrication/front_radiator_two_side_retention_rev_a/j40_front_radiator_two_side_retention_rev_a_dimension_sheet.pdf`
- `data/manual/fabrication/front_radiator_two_side_retention_rev_a/front_radiator_two_side_retention_rev_a_assembled_3d_visualisation.html`
- `data/manual/fabrication/front_radiator_two_side_retention_rev_a/front_radiator_two_side_retention_rev_a_assembled_3d_visualisation.svg`
- `data/manual/fabrication/front_radiator_two_side_retention_rev_a/front_radiator_two_side_retention_rev_a_3d_visualisation.html`
- `data/manual/fabrication/front_radiator_two_side_retention_rev_a/front_radiator_two_side_retention_rev_a_3d_visualisation.svg`
- `data/manual/fabrication/front_radiator_two_side_retention_rev_a/fabricator_cut_list.csv`
- `data/manual/fabrication/front_radiator_two_side_retention_rev_a/inspection_checklist.csv`

DXF files:
- `front_radiator_saddle_right_angle_post_rev_a.dxf` - 4 mm bolt-through saddle right-angle post, qty `1`

Release position:
- Rev A is superseded by Rev P. Its nominal dimensions, stock and geometry are not valid for purchase or fabrication.
- Historically, Rev A was a template release for one simple steel post: 90 degree top return with one radiator screw point, plus lower legs that straddle the chassis/front-support section.
- Final bending/drilling remains gated by right-side vehicle dry-fit, transferred left-bracket dimensions, screw size, radiator ear offset, chassis width, through-bolt route, crush-tube/spacer decision, rubber washer/bush stack, and fan clearance.
- The Bracket Analysis Register remains the evidence/action register; this package is the Fabrication handoff for making the bracket templates.

## Photo-Measured Retained Cooling Pack — Rev L (Current provisional mock-up issue)

**Current controlled handoff — issued 2 August 2026.** Rev L uses the newly imported tape photographs of the actual retained R0 radiator, full-face C0 condenser, large rear electric FL puller and small front FS pusher. It corrects Rev K's mechanical-fan identification and replaces nominal component sizes with photo-derived starting envelopes. These figures release only the first full-size dummy; final steel cutting still requires square direct measurements, templates and a complete opaque vehicle dry-fit.

Controlled specification: [Rev L photo-measured shop specification](J40-photo-measured-retained-cooling-pack-specification-rev-l.md)

Complete procurement list: [Rev L OEM/donor-first parts list](j40-rev-l-complete-oem-donor-parts-list-20260803.md). It covers the retained parts to bring for matching, donor/OEM candidates, all new cooling and A/C service parts, charge pipework, mounting hardware, covered fan electrics, control inputs, consumables and commissioning services.

Controlled visual set: [D19 photo-measured retained parts](../data/manual/fabrication/front_cooling_stack_rev_c/work_document_assets/rev_l_d19_photo_measured_parts.png) and [D20 measured packaging and holds](../data/manual/fabrication/front_cooling_stack_rev_c/work_document_assets/rev_l_d20_measured_packaging_and_holds.png).

Photo-referenced explanatory visualisations: [PH01 opaque assembled pack](../data/manual/fabrication/front_cooling_stack_rev_c/work_document_assets/rev_l_ph01_photo_measured_assembled.jpg), [PH02 wide component split-out](../data/manual/fabrication/front_cooling_stack_rev_c/work_document_assets/rev_l_ph02_photo_measured_exploded.jpg), [PH03 proposed later-chassis installation](../data/manual/fabrication/front_cooling_stack_rev_c/work_document_assets/rev_l_ph03_photo_measured_installed.jpg), and [PH04B corrected engine-bay-side rear-puller view](../data/manual/fabrication/front_cooling_stack_rev_c/work_document_assets/rev_l_ph04b_photo_measured_engine_side_corrected.jpg). In PH04B the engine is in the foreground, R0 is forward toward the grille, and FL is physically between R0 and the engine. These AI images explain the arrangement only; D19/D20 and the physical dry-fit control fabrication.

Release position:
- Retain and test actual R0, C0, FL, FS and the stone guard. Add only one K0 CAC and, preferably, one exact Toyota/Denso mate for FS. If an exact mate fails fit or availability, use two matching complete front modules and keep FS as the spare.
- First mock-up envelopes from the tape photographs: R0 approximately `635 W × 610 body H mm` (`≈635 mm` to cap); C0 approximately `540 W × 465 H mm`; FS guard approximately `240–255 mm` with complete frame/tabs starting estimate `≈280 mm`; FL ring approximately `450–480 mm`. All are provisional, not purchase or cut dimensions.
- Make two `≈280 mm` front-fan dummies with a `10 mm` centre gap: `2 × 280 + 10 = 570 mm`. Against the provisional `≈635 mm` R0 silhouette this gives `≈32.5 mm` equal side margins. Final release uses measured `F`, `Db`, `Wc` and `Wa`, not the photo estimates.
- Front pair is level and horizontally centred on the **vehicle centreline** within `±2 mm`. Require `2F + g ≤ Wc`, positive equal `M = (Wc − 2F − g) / 2`, and `2Db + g ≤ Wa` or a sealed plenum proven by installed airflow testing.
- Finished system has exactly three electric fans: the two equal front pushers plus retained FL rear puller. Each has its own covered fused/relay branch aligned with the existing electrical carrier; no side annex.
- Lower saddles and a full-width crossmember carry R0. Both intended top holes locate/restrain it. B0 hole centres, S0 saddle centres, every complete depth/plug/pipe/tool envelope and vehicle W0 remain HOLD until directly measured.
- Require complete installed three-fan airflow `≥3,000 m³/h` at `13.5 V` at the fan terminals (`≥3,300 m³/h` preferred) plus the instrumented `50 °C` thermal gates. Never add free-air catalogue ratings.

## Retained Original Radiator + Full-Face A/C Condenser Cooling Pack — Rev K (Superseded / History)

**Superseded by Rev L on 2 August 2026. Do not issue Rev K for fabrication or buying.** Rev K established the retained R0 and full-face C0 architecture, but incorrectly described the photographed rear FL fan as mechanical and relied on earlier nominal sizes. Its AI views remain layer-order history only; Rev L's actual photographs and D19/D20 control the provisional measurements.

Controlled specification: [Rev K source specification](J40-retained-original-radiator-and-condenser-cooling-pack-specification-rev-k.md)

Simplified donor-parts purchase list: [Rev K minimum purchase list](j40-rev-k-minimum-purchase-list-20260802.md)

Visual release and source set: [Rev K prompt log](../data/manual/fabrication/front_cooling_stack_rev_c/rev_k_actual_radiator_condenser_visual_prompts.md), [D17 measurement-control sheet](../data/manual/fabrication/front_cooling_stack_rev_c/work_document_assets/rev_k_d17_actual_parts_packaging_dimensions.png), [assembled pack](../data/manual/fabrication/front_cooling_stack_rev_c/work_document_assets/rev_k_ph01_actual_parts_assembled.jpg), [wide exploded view](../data/manual/fabrication/front_cooling_stack_rev_c/work_document_assets/rev_k_ph02_actual_parts_exploded.jpg), [later-chassis view](../data/manual/fabrication/front_cooling_stack_rev_c/work_document_assets/rev_k_ph03_actual_parts_installed.jpg), and [opaque engine-side view](../data/manual/fabrication/front_cooling_stack_rev_c/work_document_assets/rev_k_ph04_actual_parts_engine_side.jpg).

Release position:
- Retain and refurbish/recore R0 if its condition and tests earn reuse; retain the complete broad C0 if its pressure, flush, fin and fit checks pass. C0 sits in its own full-face layer directly in front of R0.
- Add exactly one heat exchanger: a shallow, low-centred K0 turbo charge-air cooler ahead of only the lower central part of C0. Its roughly `450–500 W × 150–180 H × ≤65 D` core is a mock-up starting box, not an order size.
- Historical Rev K fan instruction is superseded. Current Rev L uses three tested electric fans: two equal front pushers plus retained rear FL electric puller.
- Attach R0 at both intended top positions using vertical sleeved bolts sized only after the two original horizontal top-return holes and bush stacks are measured. Lower rubber saddles carry the weight; do not use substitute holes or force alignment.
- Keep the existing covered relay/MIDI carrier inboard and within the cooling-pack silhouette. No cutting, final welding, CAC purchase or 50 °C/turbo claim is released until the opaque 1:1 fixture proves complete envelopes, depth, pipes, latch, grille/bumper, service access, rear-fan sweep and both upper mounts.

## Retained Original Radiator & Fans Cooling Pack — Rev J (Superseded / History)

**Superseded by Rev K on 2 August 2026. Do not issue Rev J for fabrication or buying.** Rev J incorrectly represented the retained A/C condenser as a narrow half-width core beside the CAC. Historical files remain at [Rev J Word handoff](J40-retained-original-radiator-and-fans-cooling-pack-specification-rev-j.docx), [source Markdown](J40-retained-original-radiator-and-fans-cooling-pack-specification-rev-j.md), [purchase list](j40-rev-j-minimum-purchase-list-20260802.md), and [prompt log](../data/manual/fabrication/front_cooling_stack_rev_c/rev_j_existing_parts_visual_prompts.md).

## Existing Radiator Refurbishment & Turbo-Fan Cooling Pack — Rev I (Superseded / History)

**Superseded by the current Rev L photo-measured retained cooling pack on 2 August 2026. Do not issue Rev I for fabrication, buying or fan layout.** It remains design history only; its fixed unequal-front-fan and front-to-rear auxiliary-stack assumptions are not current.

Historical files: [Rev I Word handoff](J40-existing-radiator-refurbishment-and-turbo-fan-specification-rev-i.docx), [source Markdown](J40-existing-radiator-refurbishment-and-turbo-fan-specification-rev-i.md), and [purchase list](j40-rev-i-refurbishment-purchase-list-20260802.md).

## Front Cooling Stack Frame - Rev A (Legacy / Superseded)

**Superseded by the current Rev L photo-measured retained cooling pack on 2 August 2026. Do not issue Rev A as the current radiator-shop or fan specification.** It remains only as historical reference for earlier frame work.

Directory: [data/manual/fabrication/front_cooling_stack_rev_a](../data/manual/fabrication/front_cooling_stack_rev_a/README.md)

Control spec: [front-cooling-stack-fabrication-plan-20260530.md](front-cooling-stack-fabrication-plan-20260530.md)

Primary files:
- `data/manual/fabrication/front_cooling_stack_rev_a/README.md`
- `docs/l4tw-front-cooling-stack-delivery-spec-20260531.md`
- `data/manual/fabrication/front_cooling_stack_rev_a/delivery_spec_l4tw_20260531.csv`
- `docs/front-cooling-stack-local-parts-selection-20260530.md`
- `data/manual/fabrication/front_cooling_stack_rev_a/local_parts_selection_pakistan_20260530.csv`
- `data/manual/fabrication/front_cooling_stack_rev_a/known_price_fit_check_pakistan_20260530.csv`
- `data/manual/fabrication/front_cooling_stack_rev_a/front_cooling_stack_rev_a.svg`
- `data/manual/fabrication/front_cooling_stack_rev_a/component_layout.csv`
- `data/manual/fabrication/front_cooling_stack_rev_a/measurement_basis.csv`
- `data/manual/fabrication/front_cooling_stack_rev_a/fabricator_cut_list.csv`
- `data/manual/fabrication/front_cooling_stack_rev_a/inspection_checklist.csv`

DXF files:
- None in Rev A. This is a site-fit mock-up/fabricator spec because upright height, chassis saddle width, radiator tabs, condenser tabs, drier clamp, fan hoop, and hole centres must be transferred from the actual vehicle and selected parts.

Release position:
- Rev A turns the prior one-side radiator support repair into a full front cooling-stack frame when both full-height chassis/front-support uprights are being fabricated.
- It carries the HJ47/2H radiator, R134a parallel-flow condenser, optional slim pusher fan, and receiver-drier as separate rubber-isolated components.
- The L4TW delivery spec is the acceptance contract: corrected radiator, two-side frame, condenser, fan provision, drier, pressure switch, compressor gate, barrier hoses, electrical protection, and final validation evidence.
- The local buy package selects Master Radiators/KorTech for the radiator route, Snow Cool/Arsalan for condenser/drier/evaporator leads, and Sanpak/Arsalan/Cool Sun style A/C hose support, but final purchase remains gated by dimensions and fitting proof.
- The existing Sanden-type compressor is compatible in principle with the condenser/drier layout, but hose crimping and final charge remain blocked until the compressor port style, clutch voltage, belt alignment, oil/refrigerant state, leak test, and pressure-switch protection are confirmed.

## 2H Turbo-Readiness Chassis Provisions - Rev A

Current controlled build process: [2h-turbo-recommended-build-process-20260801.md](2h-turbo-recommended-build-process-20260801.md)

Illustrative build-sequence assets: [docs/images/turbo-2h-controlled-build](images/turbo-2h-controlled-build/README.md)

Current packaging matrix: [data/manual/fabrication/turbo_packaging_rev_a](../data/manual/fabrication/turbo_packaging_rev_a/README.md)

Visual guide archive: `deliverables/fabrication_packages/2h_turbo_controlled_build_visuals_rev_d_20260802.zip`

The current guide uses a four-step sequence for goods-receipt inspection, full-vehicle steering/hot-side mock-up, a paired near-side/opposite-side Rev H packaging study using recognisable real component forms, and monitored static commissioning. The current study removes the unused compact-air-cleaner alternative and provisional side/wing cooler; the archive retains the earlier cardboard-envelope studies as visual history. The relocation matrix makes retain/move/add/decision actions explicit. Every image is non-dimensional and cannot close an identity, clearance, fabrication or test gate.

Directory: [data/manual/fabrication/turbo_readiness_chassis_rev_a](../data/manual/fabrication/turbo_readiness_chassis_rev_a/README.md)

Control spec: [turbo-readiness-chassis-welder-fabrication-spec-20260717.md](turbo-readiness-chassis-welder-fabrication-spec-20260717.md)

Primary files:
- `data/manual/fabrication/turbo_readiness_chassis_rev_a/README.md`
- `data/manual/fabrication/turbo_readiness_chassis_rev_a/fabrication_scope.csv`
- `data/manual/fabrication/turbo_readiness_chassis_rev_a/inspection_checklist.csv`

DXF files:
- None. This is a measured site-fit interface release; turbo-dependent positions and hole centres must be transferred from the assembled vehicle or rigid full-size templates.

Release position:
- **Superseded as a current welder handout on 2026-07-19.** Use [chassis-welder-steering-turbo-component-first-instruction-20260719.md](chassis-welder-steering-turbo-component-first-instruction-20260719.md).
- Released now: clean/inspect/photograph the existing steering-box mount and continue unrelated approved chassis work.
- No J80 steering, battery-carrier lock or turbo conversion-specific welding is released until the actual matched component sets are present for trial fit. Use `docs/chassis-welder-j80-steering-turbo-component-first-instruction-20260802.md`; the older J60 handout is historical.
- Conditional after physical component trial fit: steering mounting/reinforcement, line/loom relocation tabs, exhaust-hanger interfaces, heat-shield interfaces and removable airbox/breather/charge-support interfaces.
- Explicitly excluded: manifold, turbo support, downpipe, complete exhaust, sump/oil-return work and charge-pipe fabrication.

## Suspension Wood Cribbing - Rev A

Directory: [data/manual/fabrication/suspension_wood_cribbing_rev_a](../data/manual/fabrication/suspension_wood_cribbing_rev_a/README.md)

Control spec: [suspension-wood-cribbing-merchant-spec.md](suspension-wood-cribbing-merchant-spec.md)

Primary files:
- `data/manual/fabrication/suspension_wood_cribbing_rev_a/j40_suspension_wood_cribbing_rev_a_dimension_sheet.pdf`
- `data/manual/fabrication/suspension_wood_cribbing_rev_a/suspension_wood_cribbing_rev_a_3d_visualisation.html`
- `data/manual/fabrication/suspension_wood_cribbing_rev_a/suspension_wood_cribbing_rev_a_3d_visualisation.svg`
- `data/manual/fabrication/suspension_wood_cribbing_rev_a/fabricator_cut_list.csv`
- `data/manual/fabrication/suspension_wood_cribbing_rev_a/inspection_checklist.csv`

DXF files:
- `swc_rectangular_cribbing_block_rev_a.dxf` - rectangular hardwood cribbing block, qty `8`
- `swc_wedge_chock_rev_a.dxf` - wedge chock side/top/end profile, qty `4`

Release position:
- Fabrication completed and closed on user confirmation dated `2026-08-16`; retain Rev A as the received-set reference.
- Drawing backup for the suspension-owned cribbing buy in [suspension-wood-cribbing-merchant-spec.md](suspension-wood-cribbing-merchant-spec.md).
- Control dimensions are metric: blocks `300 x 150 x 75 mm`; wedges `200 x 100 mm` base with `75 mm` rear height and `25 mm` nose height.
- These are supplemental cribbing/chocks only and must not be treated as substitutes for rated jack stands or axle support.

## Electrical Mounting Packages

### MIDI 5-Way Hinged Enclosure - Rev D

Directory: [data/manual/fabrication/midi5_enclosure_rev_d](../data/manual/fabrication/midi5_enclosure_rev_d/README.md)

Primary files:
- `data/manual/fabrication/midi5_enclosure_rev_d/j40_midi5_enclosure_rev_d_dimension_sheet.pdf`
- `data/manual/fabrication/midi5_enclosure_rev_d/midi5_enclosure_rev_d_3d_visualisation.html`
- `data/manual/fabrication/midi5_enclosure_rev_d/midi5_enclosure_rev_d_3d_visualisation.svg`

DXF files:
- `midi5_enclosure_body_rev_d.dxf` - `3.0 mm` 5052-H32 aluminium folded enclosure body
- `midi5_holder_subplate_rev_d.dxf` - `5.0 mm` HDPE, ABS, G10, or phenolic holder board
- `midi5_enclosure_lid_rev_d.dxf` - `2.0-3.0 mm` aluminium hinged lid

Order definitions:
- Enclosure body: finished floor `210 x 165 mm` with `65 mm` folded side walls, hinge holes on the input/bus side, latch holes on the output side, one `20 mm` input grommet pilot aligned to fuse 4 / the second-from-last holder, and five output-side grommet pilot holes.
- Far-side output hole: enlarged `28 mm` pilot for the output that carries `2` power cables. The other four output holes are `16 mm` pilots. Open every pilot to the final cable/grommet OD after measurement.
- Holder subplate: `140 x 85 mm` non-conductive board with ten `4.5 mm` holder holes on `20.2 mm` pitch / `44 mm` row separation, plus six `5.5 mm` standoff holes.
- Lid: `230 x 185 mm` aluminium cover panel with hinge holes on the input/bus side and latch holes on the output side.

Release position: current recommended MIDI holder route. The external plastic/CNC quote is still only for the holder subplate; the aluminium enclosure body and lid are owner-made or sheet-metal-shop parts. Use `10-12 mm` insulated/sleeved spacers between the holder board and enclosure floor, and fit rubber grommets before wiring.

### Relay Mount - Rev D

Directory: [data/manual/fabrication/relay_mount_rev_d](../data/manual/fabrication/relay_mount_rev_d/README.md)

Primary files:
- `data/manual/fabrication/relay_mount_rev_d/j40_relay_mount_rev_d_dimension_sheet.pdf`
- `data/manual/fabrication/relay_mount_rev_d/relay_mount_rev_d_3d_visualisation.html`
- `data/manual/fabrication/relay_mount_rev_d/relay_mount_rev_d_3d_visualisation.svg`

DXF files:
- `relay_base_plate_rev_d.dxf` - flat `360 x 245 x 3.0 mm` 5052-H32 aluminium base plate with structural-carrier-plate attachment slots
- `relay_insulating_sheet_rev_d.dxf` - exact `300 x 197 x 3.0 mm` relay-box-bottom-footprint insulating sheet

Order definitions:
- Base plate: flat aluminium only. Use exposed margins/slots to attach the relay assembly to a removable plate on the structural radiator/cooling-stack carrier; never to the core, fins, tanks, necks, seams, or through-core rods.
- Insulating sheet: sits directly between the already-covered relay/fuse box and the aluminium base. Transfer relay-box fixing holes from the actual enclosure after orientation is confirmed.

Release position: current recommended relay-box fabrication route. Rev D supersedes the folded Rev C relay carrier because the existing relay box is already a covered enclosure.

## Electrical Underlay / Insulator Requirements

These non-metal electrical underlays/guards are tracked separately from owner-made metal plates and brackets:

| Requirement | Package file | Definition | Status |
| --- | --- | --- | --- |
| MIDI holder insulating underlay / subplate | `midi5_enclosure_rev_d/midi5_holder_subplate_rev_d.dxf` | `140 x 85 x 5.0 mm` HDPE/ABS/G10/phenolic board; ten `4.5 mm` holder holes; six `5.5 mm` standoff holes. | Current external plastic/CNC quote row. |
| Relay insulating sheet | `relay_mount_rev_d/relay_insulating_sheet_rev_d.dxf` | Exact `300 x 197 x 3.0 mm` ABS/HDPE/polypropylene/G10/phenolic sheet between the existing relay box's large uncovered bottom face and the flat aluminium base. | Current relay-box underlay. |

## Superseded Electrical History

The older MIDI module packages remain in the repo as history, but should not be sent as the current fabrication route unless that older design is deliberately reopened:
- `data/manual/fabrication/midi5_module_rev_a`
- `data/manual/fabrication/midi5_module_rev_b`
- `data/manual/fabrication/midi5_plate_mount_rev_c`
- `data/manual/fabrication/relay_mount_rev_c`

## Shop Instructions

- Confirm material and thickness on the purchase order before cutting.
- Do not treat construction, bend, recess, register, insert, or template layers as through-cuts unless the package README says so.
- Wood cribbing DXFs are dimensional saw-cut/profile references for the timber/workshop package, not vehicle mounting parts.
- Deburr all metal parts and apply corrosion protection after forming.
- Trial-fit first articles before batch production or final loom/body closeout.

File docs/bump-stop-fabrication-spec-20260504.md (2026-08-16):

# J40 Bump Stop Fabrication Spec - 2026-05-04

Scope: replacement bump stops for the leaf-spring axle-to-chassis stops where Toyota supply cannot be relied on and the old rubber is too decayed to use as the mould master.

Status correction `2026-07-22`: a new four-stop set is in hand from the July 12 intake, but installation is not reported or scheduled. The owner's front/rear installation update referred to the separate vehicle bumpers. This document remains the received-part identity, dimensional, fixture, and eventual full-bump acceptance control; local fabrication is a fallback only if a received part fails those checks. When fitted, mount the stops through the correct separate chassis-side brackets/metal fixtures above the axles, not under the spring packs or U-bolt plates.

Measurement transcription `2026-08-16`: the usable May 31 tape-measure photos have now been read into the provisional dimensional register below. They support approximately `70 mm` sample height, `110 mm` metal backing/fixture length along the mounting-hole axis, `65 mm` rubber-body span along that axis, and `90 mm` mounting-hole pitch. These are photo-survey nominals, read to roughly the nearest `5 mm`, not manufacturing tolerances. Hole diameter, thread, transverse width, plate thickness, fixture-channel detail, station offsets, loaded gap, and full-bump clearance still require direct measurement. `photos/20260531_171833_gp_Vw96I7Mg.jpg` is an unrelated laptop image and is excluded from the evidence set.

This is not a Toyota engineering/mould drawing. Toyota almost certainly had a formal drawing for `48304-60010` and `48304-60020`, but the public OEM/catalog pages checked do not expose the mould dimensions, compound recipe, internal reinforcement detail, metal fixture relationship, or load/deflection curve. Treat the Toyota numbers and known application/height data as external controls. The May 31 exact front bump-stop photos now control the visible local shape: a broad molded rubber body carried by a metal backing/fixture with two exposed mounting ears, rounded/asymmetric sides, a central metal fixture/insert interface, and a flat strike face. Rear/back stops use the same front-stop shape and fixture pattern, made longer to the `70 mm` family height. Final station release still comes from calipers, the removed metal fixture, current vehicle brackets, axle strike pads, and first-article tests.

If a Toyota dealer, NOS part, or genuine sample becomes available, use it as the preferred master before cutting a mould. Until then, the fabricator must reproduce the Toyota-style progressive stop, not invent a square rubber block.

## External Reference Controls

| Controlled part | Qty | Position | Toyota reference | Free height target | Source role |
| --- | ---: | --- | --- | ---: | --- |
| `BUMP-60010-FL` | `1` | Front left spring bump stop | `48304-60010` | `70 mm` | Same May 31 front-stop shape family, made to the long height. |
| `BUMP-60020-FR` | `1` | Front right spring bump stop | `48304-60020` | `60 mm` | Exact front-stop shape from the May 31 photos at the short height. Do not substitute the `70 mm` long stop unless a full bump-clearance test proves it must be trimmed to the right-front height. |
| `BUMP-60010-R` | `2` | Rear spring bump stops | `48304-60010` | `70 mm` | Matched rear/back pair using the same front-stop body and fixture pattern, made longer. |

External references used:

- Nengun `48304-60010`: lists `SPRING BUMPER 48304-60010` as a genuine Toyota OEM part and shows Toyota Land Cruiser catalog fitment.
- ToJo 4WD Centre `48304-60010`: lists the left-front and rear axle application and `Height = 70mm`.
- ToJo 4WD Centre `48304-60020`: lists the right-front application and `Height = 60mm`, and warns that some aftermarket `48304-60020` stops are incorrectly made at the same `70 mm` height as `48304-60010`.
- Cruiser Corps long bump stop listing: states the long stop fits both rear positions and the left front, while the right-front position uses a shorter stop.

Links:

- https://www.nengun.com/oem/toyota/48304-60010
- https://www.tojo4wdcentre.com.au/part-shop/view/2008/201/parts-suitable-for-landcruiser/landcruiser-hj45-troop-4-79-7-80/48304-60010-bumper-stop-front-lh-rear-axle-t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
- https://www.tojo4wdcentre.com.au/part-shop/view/2009/85/parts-suitable-for-landcruiser/landcruiser-bj40-9-77-7-80/48304-60020-bumper-stop-front-rh-front-axle-to-chas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
- https://cruisercorps.com/products/axle-bump-stop-long

## Sample-Controlled Shape To Reproduce

The correct fabrication target is now the usable front-stop photo set shown in `photos/20260531_171824_gp_HmSS2ChQ.jpg`, `photos/20260531_171859_gp_i6bRyQKA.jpg`, `photos/20260531_171903_gp_jNI1gfYA.jpg`, and `photos/20260531_171935_gp_BYfhqiWg.jpg`. The May 29 removed-sample photos are supporting fixture and construction evidence only. The rear/back stops are the same body, metal-backed mounting pattern, fixture/channel interface, and strike-face design made longer to the `70 mm` family height. It is not a plain rubber block. Use the May 31 front-stop photos, the May 29 fixture-support photos, the removed metal fixture, the cleaned vehicle brackets, the axle strike pads, and any usable NOS/genuine sample to control the visible form:

- Molded rubber body carried by a metal backing/fixture with two exposed mounting ears. The usable photos show the mounting holes in the metal ears outside the rubber body; they do not prove through-holes in the rubber.
- Broad low body with rounded/asymmetric plan corners and battered/tapered sides copied from the better surviving sample faces, then cleaned up into a mouldable shape.
- Central metal fixture/insert interface or raised channel visible in the side view; trace the removed metal fixture and reproduce the rubber channel/relief that receives it.
- Flat/worn strike area on the lower rubber body that must land squarely on the axle strike pad.
- Radiused edges and fillets around the load path; no sharp-corner cuboid, tyre-rubber block, or stacked washers.
- Metal fixture/bracket hardware is a separate trace/reuse item. Do not replace the sample with the earlier flat-back-plate placeholder unless the actual fixture proves that construction at the vehicle.

Fabricator deliverables before mould release:

1. Sketch or CAD view of the side profile, plan view, metal mounting-hole layout, central fixture channel/insert interface, removed metal fixture trace, and rubber strike face.
2. Material declaration: rubber/PU family, Shore A target, any internal metal/reinforcement or fixture-retention method, and expected recovery.
3. Removed-sample plus vehicle measurement sheet with `BL`, `BW`, `P`, `D`, `X/Y`, `G`, `F`, and central fixture/channel values for each station.
4. First-article photos on the vehicle and a basic compression/recovery test result.

## Fabrication Route

Use a molded or cast progressive bump-stop rubber copied from the May 31 exact front-stop photo set, with the sample-proven metal backing/fixture and central metal fixture/insert interface. Rear/back stops use that same shape family at the longer `70 mm` height. Do not cut a simple solid cuboid from sheet rubber and do not rely on ordinary glue-only attachment.

Preferred material:

- New automotive bump-stop rubber, `NR/SBR` or equivalent suspension bump-stop compound.
- Hardness target `70 +/-5 Shore A`.
- Tensile strength target `>=10 MPa`.
- Elongation at break target `>=300%`.
- Compression set target `<=30%` after `22 h` at `70 C` and `25%` deflection if the compound supplier can certify it.
- Exterior underbody service: oil splash resistant enough for chassis use, ozone/weather protected, no tyre rubber, crumb rubber, sponge, mixed offcuts, salvage rubber, or unmarked compound.

Acceptable local fallback:

- Cast automotive polyurethane only if the fabricator cannot mould rubber and can keep the same progressive geometry, fixture/captive construction, and rebound recovery.
- Hardness target `80 +/-5 Shore A` for PU.
- Make the four stops as one batch and trial-fit before accepting final production.
- PU fallback must still use the May 31 front-stop rounded/tapered body, metal-backed mounting pattern, central fixture/interface detail, correct height, and strike-face location. A cast square block is not acceptable.

## Vehicle-Controlled Mould Dimensions

The old rubber is now construction evidence, not a finished dimension master. Release these values from the May 31 exact front-stop photos, the May 29 fixture-support photos, the removed metal fixture, the actual vehicle brackets, and the strike pads, in millimetres.

| Measurement ID | Measurement | How to take it | Controls |
| --- | --- | --- | --- |
| `BL` | Metal backing/fixture overall length along the mounting-hole axis | Use the photo-survey nominal below for screening; caliper the better surviving sample, the removed metal fixture, and cleaned bracket landing for release. | Metal backing outline, mould base, and fixture seat. |
| `BW` | Rubber body / fixture landing width | Caliper the better surviving sample and usable bracket/fixture width at the seating face. | Rubber body width and central fixture/channel clearance. |
| `P` | Metal fixture mounting-hole pitch | Use the photo-survey nominal below for screening; measure centre-to-centre across the two metal mounting ears and confirm against the vehicle holder. | Fixture alignment. |
| `D` | Metal mounting-hole diameter and fitted bolt/stud/thread size | Caliper the metal holes and identify the fitted thread with a thread gauge. Do not infer this dimension from bolt colour or the oblique tape photos. | Hole clearance, thread engagement, and fastener control. |
| `X/Y` | Strike-pad centre offset | With the axle under the stop, mark the centre of the axle contact pad relative to the metal mounting holes and fixture/bracket bolt features. | Rubber contact face location. |
| `G` | Loaded stop gap | With the Ironman suspension fitted, tyres on ground, normal vehicle load, measure mount face to axle strike pad. | Ride-height clearance check. |
| `F` | Full-bump limiting clearance | Jack the axle upward safely until the earliest limit is near: shock bottoming, tyre/body contact, spring/shackle bind, brake hose strain, or metal contact. | Confirms the stop touches before any hard limit. |
| `C` | Compressed stop allowance | Compress first article on a press to `50%` height and check no cracking, delamination, or permanent collapse. | Progressive compression and rebound acceptance. |

### Photo-Derived Dimensional Register

| Dimension | Provisional nominal | Photo evidence | Confidence / release rule |
| --- | ---: | --- | --- |
| Long-family sample free height | `~70 mm` | `20260531_171935_gp_BYfhqiWg` | High read confidence; worn sample and tape alignment mean this is an identity check only. Released production height remains `70 +/-1 mm` from the Toyota-family control. |
| Metal backing/fixture overall length along mounting-hole axis (`BL`) | `~110 mm` | `20260531_171859_gp_i6bRyQKA`, `20260531_171903_gp_jNI1gfYA` | Moderate confidence; oblique views. Use to identify/screen the received part, then verify with calipers before fabrication. |
| Molded-rubber span along mounting-hole axis | `~65 mm` | `20260531_171824_gp_HmSS2ChQ` | Moderate-to-high confidence; tape is close to square-on. This is the rubber span between the exposed metal ears, not the transverse body width. |
| Metal mounting-hole pitch (`P`) | `~90 mm c-c` | `20260531_171859_gp_i6bRyQKA`, `20260531_171903_gp_jNI1gfYA` | Moderate confidence; estimated from two oblique tape views. Confirm directly on the received stop and threaded holder before selecting hardware. |
| Metal mounting-hole diameter (`D`) | `not released` | Hole openings are visible, but the tape views do not resolve diameter accurately. | Caliper required. Do not use a visual estimate as an `M8` confirmation. |
| Fitted holder thread | `not released` | No measurement photo shows a thread gauge or known bolt diameter/pitch. | Identify with a known fastener or thread gauge; confirm adequate engagement and no bottoming. |
| Transverse body/fixture width (`BW`) | `not released` | No square-on tape view across the transverse axis. | Caliper required. |
| Plate thickness, fixture/channel detail, `X/Y`, `G`, `F`, and `C` | `not released` | Not dimensionally resolved by the available tape photos. | Direct part/vehicle measurement and first-article test required. |

The approximation symbol above means a photo reading to about the nearest `5 mm`; it is not a `+/-5 mm` manufacturing tolerance. Do not scale dimensions from the apparent pixel size of the oblique photos.

Geometry release rules:

- The `P` and `D` dimensions on `data/manual/fabrication/rubber_recreation_rev_a/bump_stop_vehicle_measurement_control.svg` / `.dxf` are metal mounting-hole plus fixture/bracket controls. These drawings are measurement controls only; they are not a released final cut profile until the direct sample, fixture, and bracket values are recorded.
- Base footprint: copy the May 31 exact front-stop family, then confirm it seats with the removed metal fixture and vehicle bracket with `0.5-1.0 mm` practical edge clearance where needed.
- Mounting holes/studs: use the metal backing/fixture ears and vehicle `P` and `D`; feature location tolerance `+/-0.5 mm` applies only after direct measurement release. The photos do not show or prove holes through the rubber body.
- Rubber height: `70 +/-1 mm` for `BUMP-60010-FL` and both `BUMP-60010-R`; `60 +/-1 mm` for `BUMP-60020-FR`. Height changes only stretch the same front-stop body family; do not create a separate rear shape.
- Matched rear pair: rear left and rear right free height must match within `1 mm`, and hardness readings must be within `5 Shore A`.
- Contact face: centred on the axle strike pad within `+/-5 mm`; face must be radiused/tapered, not a sharp-edged block.
- Side profile: taper the body so compression is progressive and so the rubber does not foul the mount, U-bolts, spring pack, shock, or tyre through axle movement.
- Vehicle bracket and removed metal fixture: clean and inspect before mould release. Repair chassis/bracket/fixture metal only under a separate metal-fabrication release; the bump-stop part itself is the molded rubber sample family with its metal-backed mounting ears and central fixture interface.

## First Article Test

Make one `70 mm` long stop first and one `60 mm` right-front stop first. Do not make the full set until both pass.

Acceptance:

1. The metal mounting holes align with the vehicle holder/bracket, bolts/studs pass by hand without forcing or bottoming, and the central fixture/interface is captured without tearing or rocking.
2. Contact face lands on the axle strike pad within `+/-5 mm`.
3. Stop engages before shock bottoming, tyre/body contact, spring/shackle bind, brake hose strain, or metal-to-metal contact.
4. Compressed to `50%` of free height on a press, the rubber shows no cracking, tearing, bond/captive failure, or permanent collapse.
5. After `30 min` unloaded at room temperature, height recovery is at least `90%`.
6. Installed stops do not foul brake hoses, hard lines, U-bolts, shocks, tyres, springs, or steering through the checked travel range.

Reject:

- Any `BUMP-60020-FR` made at `70 mm` unless it is deliberately trimmed/released from the vehicle full-bump test.
- Any simple cut block, square tyre-rubber pad, reused rubber, or universal stop whose contact point misses the axle pad.
- Any part with cracks, voids larger than `1 mm` on a load face, loose retention feature, visible filler chunks, oily bleed, tacky uncured surface, or mismatched height/hardness across an axle pair.
- Any part whose fixture interface tears, whose rubber separates from any retained insert/fixture, whose holes do not match the sample/vehicle pitch, or whose molded body reverts to the earlier flat-plate placeholder.

## Photo And Measurement Capture

For each station, take these before ordering the mould:

1. Wide photo showing which station it is: front-left, front-right, rear-left, rear-right.
2. Square-on photo of the cleaned mounting bracket with a ruler/caliper visible.
3. Close photo of the bolt holes/studs with the ruler across the centres.
4. Side photo showing bracket face, axle strike pad, and current gap.
5. Photo at axle-jacked near-full-bump showing the stop path and nearby shock, brake hose, spring, and tyre clearance.

Record the values in `data/manual/bump_stop_fabrication_specs.csv` or on the shop drawing before mould release.

## Existing Project Photos To Use

Use these only as station/context references. They are not dimension masters; final measurements still require ruler/caliper photos at each bracket.

| Photo | Use |
| --- | --- |
| `photos/20260501_193841_gp_ZwpHFiMA.jpg` | Current chassis/axle context after brushing; use to locate bracket and strike-pad area before close measurement. |
| `photos/20260501_193847_gp_uHWO7Bdw.jpg` | Second current-chassis angle for front/rear axle travel path context. |
| `photos/20260422_004254_gp_SplHLSYA.jpg` | Body-off underside context for spring/shackle/axle clearance. |
| `photos/20260422_004423_gp_B1N5ThVw.jpg` | Front frame-horn and suspension context; use only for orientation. |
| `photos/20260531_171824_gp_HmSS2ChQ.jpg` | Exact front bump-stop face/width measurement with tape; active mould-shape reference. |
| `photos/20260531_171833_gp_Vw96I7Mg.jpg` | Excluded: unrelated laptop image; not bump-stop evidence. |
| `photos/20260531_171859_gp_i6bRyQKA.jpg` | Front bump-stop metal fixture overall length and mounting-hole pitch measurement. |
| `photos/20260531_171903_gp_jNI1gfYA.jpg` | Companion exact front bump-stop base/fixture plate measurement. |
| `photos/20260531_171935_gp_BYfhqiWg.jpg` | Exact front bump-stop side height/profile measurement; rear/back stops use this same shape made longer. |
| `photos/20260529_223605_gp_CklgF0cQ.jpg` | Supporting removed-sample face/plan view; confirms the broad rounded body and metal-backed mounting arrangement. |
| `photos/20260529_223701_gp_wYPExcAA.jpg` | Supporting removed-sample side view for central fixture/channel interface, not the active shape master. |

Before mould release, take station-fit photo sets for front-left, front-right, rear-left, and rear-right, each with a ruler/caliper on the bracket holes and a side view of the axle strike pad. These photos verify mounting and clearance; they do not replace the May 31 front-stop shape master.

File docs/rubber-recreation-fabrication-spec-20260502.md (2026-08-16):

# Rubber Recreation Fabrication Spec - 2026-05-02

Scope: custom recreation of the J40 body-mount/front-support rubber parts from the May 2 tape-measure photos.

Source image set: Google Photos import `20260502T013759`.

Data table: `data/manual/rubber_recreation_fabrication_specs.csv`.

Toyota OE/EPC cross-reference: `data/manual/rubber_recreation_toyota_oe_cross_reference.csv`.

Aftermarket dimension cross-check: `data/manual/rubber_recreation_aftermarket_dimension_crosscheck.csv`.

Exact measurement closure table: `data/manual/rubber_recreation_measurement_closure.csv`.

Manufacturing requirements table: `data/manual/rubber_recreation_manufacturing_requirements.csv`.

## Release Position

This is the supporting fabricator handoff spec for quotation, first-article cutting, and sample preparation. For the current supplier order, `docs/longman-rubber-order-spec-20260508.md` is the primary order document.

The old-rubber photos and ruler measurements are accepted as the dimensional basis for quote and first articles. Do not treat the remaining gates as missing rubber dimensions: they are station mapping, dry-stack, caliper, and final install checks before full production or final trimming.

Toyota-style catalog data has been checked and added as a control reference. It confirms OE part numbers, station codes, left/right required quantities, bolt families, and several shim/spacer thicknesses. It does not publish rubber cushion OD, ID, free height, durometer, or cup geometry, so the rubber fabrication dimensions remain image-derived and must be closed from the physical samples.

All dimensions are in `mm`.

## Fabrication Drawing Package

Ready-to-run Rev A drawing package: `data/manual/fabrication/rubber_recreation_rev_a/`.

Send these files to the rubber/steel fabricator:

1. `j40_rubber_recreation_rev_a_dimension_sheet.pdf` - human-readable drawing pack.
2. `machine_definitions.csv` and `machine_definitions.json` - CNC/shop geometry, coordinate systems, tolerances, and non-CNC purchase controls.
3. `fabricator_cut_list.csv` - part, quantity, material, file, and release-status list.
4. `inspection_checklist.csv` - receiving and first-article inspection checks.
5. All `*.dxf` files in the package - CAD/CAM cut geometry.
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

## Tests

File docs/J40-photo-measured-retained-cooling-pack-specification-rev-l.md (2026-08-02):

# J40 photo-measured retained cooling pack — Rev L

**Issue:** 2 August 2026<br>
**Procurement schedule updated:** 3 August 2026<br>
**Vehicle/duty:** Toyota J40, Toyota 2H turbo plan, 150 bhp maximum, 50 °C ambient acceptance<br>
**Status:** measured-part layout and shop mock-up issue; final fit and thermal release remain HOLD<br>
**Supersedes:** Rev K, which treated the photographed large rear fan as mechanical and used earlier nominal part dimensions

## 1. Simple instruction for the radiator shop

Reuse and refurbish the actual project parts:

1. **R0:** original copper/brass engine-coolant radiator.
2. **C0:** original broad A/C condenser with its pipes, receiver/drier and brackets.
3. **FL:** original large electric fan and full shroud; intended as the rear puller only if its label, condition, current, rotation and airflow tests pass.
4. **FS:** original small electric fan; reuse at the front only if its complete measured frame fits the symmetric twin-fan limit below.
5. **G0:** original removable stone guard.
6. **E0:** existing aligned relay/MIDI-fuse carrier; add capacity inside the same silhouette and keep all live studs under a lid.

Add only:

- **K0:** one shallow, low-centred turbo charge-air cooler (intercooler/CAC); and
- either one true matching small Toyota/Denso fan, or two matching Toyota/Denso fans if no true mate is available or the measured pair misses the released envelope.

“Add only” above describes the functional heat exchangers and fans; it does not omit the new hoses, charge pipes, mounting rubbers, A/C service parts, covered protection, wiring, fasteners, seals and commissioning materials required in Section 9.

The required air path is:

**grille → stone guard → two equal centred front electric pushers → low-centred K0 → full-face C0 → full-face R0 → sealed FL electric puller/shroud → engine**

There are three electric fans in the finished pack. There is one engine-water radiator (R0), one A/C condenser (C0) and one turbo intercooler (K0). Do not add a second water radiator or a second condenser.

> **Karigar ke liye:** Asal bara radiator R0, poora A/C condenser C0, bara electric fan/shroud FL aur stone guard ko repair karke dobara istemal karo. Sirf aik naya intercooler K0 neeche centre mein lagao. Aagay do bilkul aik-jaisay chhotay electric fan gaari ki centre line par barabar lagain. Bara fan peechay shroud mein engine ki taraf hawa kheenche. Teenon fan ke alag relay aur covered fuse hon. Neeche ke do rubber saddles radiator ka wazan uthayen; upar ke dono asal holes sirf radiator ko seedha aur mazboot rakhen. Baaqi HOLD naap gaari par lene ke baad hi cutting/welding karo.

## 2. What the new measurement photos establish

All values below are approximate photo readings, not catalogue claims. Green/LOCKED means the tape endpoints are sufficiently clear for mock-up. Amber/PROVISIONAL means the number is useful for a cardboard model but must be remeasured square-on. Purple/HOLD means the photos do not establish it.

| Part / datum | Photo-backed result | Control status and shop use |
| --- | --- | --- |
| R0 body height | approximately **610 mm** from bottom to top tank | **LOCKED for mock-up.** Recheck before making final ears. |
| R0 highest point | approximately **635 mm** at filler/cap | **LOCKED for mock-up.** The vehicle envelope must clear this height plus cap-removal hand space. |
| R0 photographed horizontal span | approximately **635 mm** from the photographed left hook datum to the right rail | **PROVISIONAL.** The image is oblique and the hook datum is not a controlled shop face. The 29-inch mark is beyond the radiator and is not its width. Record true rail-to-rail and maximum-ear width as WR before cutting. |
| R0 active face | visually about **590 × 510 mm** | **ESTIMATE ONLY.** Measure the actual fin opening; do not order fans or a core from this estimate. |
| C0 body | approximately **540 mm wide × 465 mm high** | **LOCKED for mock-up.** Width includes the photographed right drier/manifold area but not every projecting left bracket or tool sweep. |
| FL large electric fan | ring approximately **450–480 mm**; shroud height roughly follows the 610 mm R0 body | **PROVISIONAL.** Record complete width, height, depth, label, plug, rotation, current and airflow. |
| FS small electric fan | ring approximately **240–255 mm**; full tabs/frame may reach about **280 mm** | **PROVISIONAL.** Complete frame, not blade diameter, controls whether a matching pair fits. |
| Depths and vehicle holes | not established | **HOLD.** No photo proves total stack depth, top-hole centres, lower-saddle centres or later-chassis fit. |

Source photos:

- [R0 horizontal tape](../photos/20260802_232550_gp_0Sn0iJxA.jpg)
- [R0 body and cap height](../photos/20260802_232632_gp_4XXz0OKw.jpg)
- [FL large electric fan and shroud](../photos/20260802_232749_gp_PFeZVbxw.jpg)
- [FL oblique depth context](../photos/20260802_232815_gp_7CfgOMrg.jpg)
- [FS small electric fan](../photos/20260802_232952_gp_vAD13nQw.jpg)
- [C0 width](../photos/20260802_233104_gp_pZK04oCw.jpg)
- [C0 height](../photos/20260802_233119_gp_Vdim807g.jpg)
- [C0 width confirmation](../photos/20260802_233132_gp_wUmuC2xw.jpg)

## 3. Centred front-fan release

The photos support a useful first full-size dummy, but not a purchase or cutting size:

- photographed FS complete frame/tabs: about **F = 280 mm**;
- two equal frames plus preferred centre gap **g = 10 mm**: about **570 mm** complete pair width; and
- photographed R0 left-hook datum to right rail: about **635 mm**, provisionally giving about **32.5 mm** at each side when the pair is centred.

This makes the retained FS plus one true matching fan a credible first choice. The circular guard is only about 240–255 mm, however, and the swept blade diameter is smaller again. The fan pair must therefore be checked against both the complete vehicle/radiator envelope and the usable ducted core face; the approximate 540 mm C0 body dimension alone is not the fan-carrier width.

For the measured vehicle fixture, define:

- **Wc:** usable centred carrier width inside both the measured vehicle opening W0 and the complete R0 silhouette;
- **F:** complete width of one fan module, including frame, tabs, motor, plug and required cable bend;
- **Db:** actual swept blade diameter, excluding the guard/frame;
- **Wa:** measured active or properly sealed/ducted heat-exchanger face width;
- **g:** clear gap between complete modules, preferably 10 mm; and
- **M = (Wc − 2F − g) / 2:** equal left/right carrier margin.

Release the pair only when:

- **2F + g ≤ Wc**, M is positive and left/right margins match within 2 mm;
- the two complete modules, labels, guards, motors, plugs and mounting tabs are physically identical;
- both fan centres are level within 2 mm and their midpoint is on the vehicle centreline within 2 mm;
- **2Db + g ≤ Wa**, unless a tested sealed plenum demonstrates even flow over the required face;
- both push air from grille toward engine at their installed polarity;
- no frame, plug, cable bend or electrical item projects beyond the released W0/R0 front-view envelope; and
- the complete three-fan cooling pack delivers at least **3,000 m³/h installed airflow at 13.5 V at the fan terminals**, with **3,300 m³/h preferred**, through the finished guard/core stack.

Do not add free-air catalogue figures together. Measure installed system airflow or pressure/velocity over a defined face.

Prefer one exact tested FS mate because that reuses the existing part and gives the symmetric appearance requested. If no exact mate exists, either fan fails, or the complete measured pair misses Wc/Wa, buy two matching Toyota/Denso modules and retain FS as a tested spare. Do not cut a safety guard, mix different fans, or rely on a donor vehicle name as proof of fit.

## 4. Heat-exchanger layout and starting envelope

### R0 engine radiator

- Retain the original tanks, filler/cap, necks, rails, ears and lower locators if sound.
- Clean, inspect, pressure-test and flow-test it before deciding whether to rod, repair or recore.
- It remains the only engine-coolant radiator.
- Use the photo-backed 610 mm body and 635 mm cap heights for the first physical fixture.
- Final width, depth, neck map, ear coordinates and locator coordinates remain HOLD.

### C0 A/C condenser

- Retain the full approximately 540 × 465 mm condenser body, pipes and brackets if they pass flush, fin and pressure checks. Keep the photographed receiver/drier/manifold as the mock-up geometry sample.
- Because the A/C circuit is expected to be opened for this work, fit a **new** compatible receiver/drier/desiccant element and new seals at final assembly; never install a used donor drier. If the drier is integral, the A/C specialist must specify the correct service element/procedure.
- Mount it directly in front of R0 on independent removable brackets.
- Do not crop it, turn it into a half-width unit, or hang K0 from it.

### K0 turbo CAC

Use a cardboard starting box of approximately:

- **450–500 mm core width**;
- **150–180 mm core height**; and
- **no more than about 65 mm core depth**.

This is not a purchase dimension. Tanks, ports, beads, brackets and charge-pipe bends make the complete unit larger. Buy K0 only after the opaque 1:1 vehicle fixture proves its complete envelope low and centred, within W0, without blocking service access or extending at either side.

## 5. Mounting and load path

R0 must be visibly attached at the intended top holes and fully supported below:

**R0 lower locators → two Toyota-pattern rubber saddles → full-width lower crossmember → gusseted/removable connections → both structural side uprights**

- Both lower locators sit fully in rubber saddles. No tank, soldered seam or fin carries weight.
- Start the fixture with 40 × 40 × 3 mm mild-steel SHS only if clear span is no more than 700 mm and filled R0 mass is no more than 35 kg; otherwise recalculate before fabrication.
- Both existing inward-facing top holes must be used through short removable radiator ears, sleeved EPDM bushes, washers and locking nuts.
- The two top stays locate and restrain R0; they do not carry its filled weight.
- Make one rigid two-hole B0 template. Drill removable ears only after the actual R0 sits naturally on both saddles.
- Do not slot, ream, drill new chassis holes, side-bolt as a substitute, or pull the radiator into alignment.
- C0, K0, both front fans, FL/shroud and E0 each have independent removable supports.

Before paint, weigh R0 filled and capped. Proof-load the lower cradle at the two saddle centres to twice that mass for 10 minutes. PASS requires no permanent set, cracked weld, loosened fastener, saddle movement or upright distortion.

## 6. Three electric fans and covered protection

Treat FL as a retained electric fan because the new photo shows its motor and wiring. Do not call it mechanical.

- **F1:** left front pusher, independent relay/fuse/earth.
- **F2:** right front pusher, independent relay/fuse/earth.
- **FL:** large rear puller candidate, independent relay/fuse/earth.

For every fan, record label/part number, condition, start current, stabilized current, polarity, rotation, installed direction and voltage at the motor under load. FL remains behind R0 only if it pulls toward the engine in its designed direction and the sealed shroud clears the radiator, hoses, engine and service tools. Do not reverse a fan casually; blade and shroud design may be directional.

Use three separately protected branches sized from measured current and voltage drop. Retain E0’s current aligned inboard location if possible. If a third branch will not fit, extend the carrier upward or inward inside the released front-view silhouette; never add a side fuse annex. Every MIDI fuse, bus and live stud must be under a splash-resistant removable cover with down/rear cable exits and a proven lid/service sweep.

Suggested logic:

- A/C demand/high-side pressure may request F1/F2.
- Coolant temperature may stage F1/F2, then FL.
- High IAT/boost/high load may request F1/F2 and FL.
- High coolant temperature, high A/C pressure, sensor/control fault or manual emergency override commands all three.

Final logic must fail safe without hiding a cooling fault.

The final electrical purchase includes three correctly rated sealed relay/base positions, three covered MIDI/maxi branch-fuse positions, calculated main-feed protection, new automotive cable/earths/terminals/seals and a documented control strategy. Retain any sound E0 parts only after their ratings and condition are proven; buy only the missing positions needed to total three independent branches.

## 7. Depth and remaining mandatory measurements

Before ordering K0, fan modules, hoses or final brackets, record these on the actual vehicle:

| ID | Required measurement / proof |
| --- | --- |
| WR / DR | R0 true maximum outside width and depth, including ears, necks, cap and FL/shroud. |
| WC / DC | C0 complete outside width and depth, including both brackets, drier, pipes, ports and A/C-tool sweep. |
| WF / HF / DF | FS and FL complete frames, tabs, guards, motors, plugs and cable bends. |
| W0 | Clear vehicle width at top, middle and bottom with grille, bumper, latch, uprights and wiring represented. |
| P0-upper | Guard-to-engine available depth above K0. |
| P0-lower | Guard-to-engine available depth through the K0 overlap zone. |
| B0 | Both top-hole diameters and XYZ centres using one rigid template. |
| S0 | Both lower-locator and saddle centres, diameters and installed rubber height. |
| L0 | Crossmember clear span and both end-connection geometries. |
| MR | Filled and capped R0 mass. |
| Service | Cap removal, drain, hose, A/C fitting, drier, fan plug, fuse-lid, belt/tool and core-removal sweeps. |

Required depth checks:

- upper zone = guard + front fans/carrier + clearance + C0 + 10–15 mm separation + R0 + FL/shroud + engine/service clearance;
- lower zone = upper zone + complete K0 depth + both K0 anti-contact/service gaps.

PASS only when the opaque 1:1 assembly fits with grille, bumper, bonnet/latch, pipes, hoses, wiring, lids, tools and engine movement represented. These photos do not yet prove that.

## 8. 50 °C and turbo performance release

The design target remains operation at 50 °C ambient without cooling-limited use inside the agreed 150 bhp turbo envelope. It is not achieved by dimensions alone.

Acceptance requires:

- R0 heat rejection at least **115 kW continuous** and **130 kW for 10 minutes** at the defined test duty;
- post-CAC intake temperature no higher than **80 °C** at the agreed boost/load point;
- complete charge-route pressure drop no higher than **10 kPa** at that point;
- no progressive coolant, IAT or A/C high-side-pressure rise at hot idle with A/C operating;
- stable system voltage, fan current, cable/fuse/relay temperature and installed airflow;
- no contact, leakage, vibration, blocked service access or boost/load derate caused by cooling inside the accepted envelope.

Instrument ambient, coolant inlet/outlet, pre/post-CAC IAT, boost, EGT, A/C high-side pressure, fan commands, system voltage and each fan current. Use a controlled 50 °C cell or a documented equivalent heat-soak/load simulation followed by the hottest available loaded road test.

If the low triple-overlap region causes progressive coolant temperature, A/C pressure or IAT, stop. First correct core condition, fan direction, sealing and ducting. If it still fails, relocate K0 to independently supplied air or engineer a water-to-air system under a new revision; do not shrink C0 or increase boost to hide the result.

## 9. Complete OEM/donor-first parts schedule

The separate [complete Rev L parts list](j40-rev-l-complete-oem-donor-parts-list-20260803.md) is the buyer’s check sheet. It gives quantities, source preference and the release condition for every row. The following summary is mandatory scope, not an optional suggestion:

| Group | Required new / donor-first scope | Source and release rule |
| --- | --- | --- |
| Matching front fan | One exact mate to retained FS preferred, giving two installed front fans; otherwise two identical replacement modules with FS retained as the spare | Search Toyota/Denso Prado, Land Cruiser, Hilux, HiAce and similar breaker stock using the physical FS sample. Donor name is not proof: match label, complete frame/tabs, guard, motor, blade, plug, depth, rotation and current. The finished vehicle always has two equal front fans. |
| Fan plugs and mounts | Matching connector shells, new terminals/seals, and the donor-pattern mounting grommets/shoulder sleeves | Donor shells/tails may identify and mate the connector; final terminals, seals and high-current cable are new. |
| K0 and charge route | One shallow K0, complete beaded charge pipe, reinforced silicone couplers, T-bolt clamps, supports, isolators and test ports/plugs | A pressure-tested Toyota turbo-diesel donor core may be used only if its full envelope passes the fixture; otherwise buy a new core to the released drawing. Couplers and clamps are new. |
| R0 mounting | Two new Toyota/J40-pattern lower rubber saddles; two new upper EPDM bush/crush-sleeve/washer/locking-fastener sets | Match R0 locator pins and the B0/S0 templates. Lower saddles carry weight; upper stays locate only. |
| C0/K0 mounting | New rubber isolators/shoulder sleeves for all released C0 and K0 support points | Toyota/Denso-pattern rubbers are preferred when the sample dimensions match; otherwise use new automotive EPDM and sleeves. |
| Coolant service pack | New moulded upper/lower/overflow hoses, constant-tension clamps, approved-pressure radiator cap, Toyota 2H thermostat and seal, compatible long-life coolant and deionised water if required | Genuine Toyota or documented OE-supplier parts preferred. Exact hose bends/IDs and cap pressure wait for the real neck map/system decision; do not use unknown donor caps, thermostats or hoses. |
| A/C service pack | New receiver/drier or service element, new HNBR seals/O-rings and service caps, correct oil/refrigerant, evacuation and recharge | The existing C0/drier controls geometry only. Identify refrigerant/oil and every fitting from the actual system; no used drier. |
| Three fan branches | Enough new OE-grade sealed relays/bases and covered MIDI/maxi holders/fuses to total three independent branches, plus main-feed protection as calculated | Toyota/Denso, Hella, Bosch, Littelfuse, Bussmann or equivalent documented parts; current and fuse values remain HOLD until measurement/calculation. |
| Fan controls and wiring | Documented coolant/A/C/high-IAT-or-load/fault logic, manual test/override, matching sensors/adapter, new automotive cable/earths/connectors/lugs/heat-shrink/conduit/grommets/P-clips | A Toyota/Denso switch is preferred only if its thread, thresholds and logic are documented for this system; otherwise use a reputable sealed programmable controller. |
| Fabrication hardware | New class 8.8 fasteners, washers, locking nuts, crush sleeves/spacers, EPDM sealing foam, edge trim, heat/anti-chafe protection, structural steel/gussets and corrosion coating | Final sizes come from the real B0/S0/vehicle drawings. No structural self-tappers, through-core ties or fastener compressed through rubber without a sleeve. |
| Condition-only replacements | R0/C0/FL replacement, full two-fan replacement pair, overflow bottle, or higher-output Toyota/Denso alternator with matching pulley/bracket/cable protection | Buy only when the retained part or hot-idle output test fails. A donor alternator is selected by mount, pulley, idle output and electrical data—not donor name. |

Used donor parts are appropriate for the matched complete fan module, sound connector housings, exact-pattern mounting pieces and an optional compatible overflow bottle. Receiver/drier/desiccant, O-rings, hoses, silicone couplers, clamps, cap, thermostat, coolant, high-current cable, terminals, fuses and relays must be new or documented unused OE stock.

> **Simple buyer rule:** take R0, C0, FL, FS, E0 and the B0/S0 templates to the shop. Buy by physical sample, complete dimensions, direction and rating—not by “Prado” or “Land Cruiser” wording alone.

## 10. Shop sequence

1. Put the actual R0, C0, FL/shroud, FS, G0, E0 and vehicle together.
2. Mark each part ID and record every HOLD dimension above.
3. Test R0, C0, FL and FS; stop or repair if a retained part fails.
4. Make the B0 and S0 rigid templates and the lower-load fixture.
5. Make two full-size fan dummies from the measured FS envelope (about 280 mm each as photographed), with the actual plug and cable-bend space, plus one complete K0 dummy.
6. Build the opaque full-size stack and prove width, depth, top holes, lower load path, service sweeps and removal paths.
7. Choose one FS mate only if the complete pair passes; otherwise choose two equal narrow donor fans.
8. Buy K0 and fabricate independent removable brackets only after the fixture passes.
9. Complete pressure/flow/electrical/installed-airflow tests, then the instrumented 50 °C acceptance test.
10. Record photos and results before paint and final sign-off.

## 11. Controlled drawings

- [D19 photo-measured retained parts](../data/manual/fabrication/front_cooling_stack_rev_c/work_document_assets/rev_l_d19_photo_measured_parts.png)
- [D20 measured packaging and release holds](../data/manual/fabrication/front_cooling_stack_rev_c/work_document_assets/rev_l_d20_measured_packaging_and_holds.png)

Photo-referenced Rev L explanatory visualisations:

- [PH01 opaque assembled pack](../data/manual/fabrication/front_cooling_stack_rev_c/work_document_assets/rev_l_ph01_photo_measured_assembled.jpg)
- [PH02 wide component split-out](../data/manual/fabrication/front_cooling_stack_rev_c/work_document_assets/rev_l_ph02_photo_measured_exploded.jpg)
- [PH03 proposed later-chassis installation](../data/manual/fabrication/front_cooling_stack_rev_c/work_document_assets/rev_l_ph03_photo_measured_installed.jpg)
- [PH04B corrected engine-bay-side rear-puller view](../data/manual/fabrication/front_cooling_stack_rev_c/work_document_assets/rev_l_ph04b_photo_measured_engine_side_corrected.jpg)

These four AI-generated images are based on the actual retained-part and chassis photographs and may be used to understand arrangement and appearance only. PH04B is deliberately viewed from inside the engine bay: the engine is nearest the camera, the large electric FL puller is between the engine and R0, and R0 is farther forward toward the grille. Never trace an AI image for cutting or treat it as proof of fit. The real parts, direct square measurements, D19/D20, rigid templates and complete opaque vehicle dry-fit control fabrication.

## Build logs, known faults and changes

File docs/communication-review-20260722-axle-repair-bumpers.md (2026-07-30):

# Communication Review - Axle Repair And Vehicle Bumpers - 2026-07-22

## Result

No email or newly available WhatsApp message independently confirms the `2026-07-22` grinder-cut repair or the scheduled front/rear vehicle-bumper installation. The owner's direct project update and the two supplied design-reference images are the authoritative evidence for those status changes.

The front and rear vehicle bumpers are separate from the four rubber suspension bump stops. The bump stops remain received but not installed.

## Sources Checked

- A Gmail search of the connected Akbar Khan account for J40/FJ40, Land Cruiser, axle, suspension, grinder, weld/welder, bumper, bump stop, Ironman, `48304-60010`, and `48035-60010` returned no matching email.
- The locally imported David Pridmore project-mail archive through `2026-07-20` was checked for the same subjects. The only apparent grinder matches were order/delivery notices for angle-grinder accessories; they do not evidence the vehicle damage or repair and were excluded.
- The WhatsApp MCP project import was rerun on `2026-07-22`. Both configured profiles were disconnected, so the importer retained the previous export: `2,444` messages and `436` media items, newest message `2026-06-13T10:49:27Z`.
- Older WhatsApp message `fj40-00052` (`2026-03-13`) says to put the full-width front body bumper back. It supports the historical vehicle-bumper intent, but it is not proof of the current fabrication or installation state.
- `photos/20260722_front_vehicle_bumper_design_reference.png` and `photos/20260722_rear_vehicle_bumper_design_reference.png` record the supplied front and rear design references. They are visual concepts, not dimensional drawings or recovery/tow-rating evidence.

## Evidence Keys Added To Project Status

- `user_update_2026-07-22_axle_grinder_cut_repair_reported_complete`
- `user_clarification_2026-07-22_vehicle_bumpers_install_planned_separate_from_bump_stops`
- `20260722_front_vehicle_bumper_design_reference`
- `20260722_rear_vehicle_bumper_design_reference`
- `comms_review_2026-07-22_axle_repair_bumpers`

The weld repair remains pending inspection/photo/coating closeout. Both vehicle bumpers remain pending installed fit, chassis-pickup, weld, access/clearance, and recovery/tow/load-path validation. The bump stops remain pending eventual bracket/fixture fit and full-bump checks.

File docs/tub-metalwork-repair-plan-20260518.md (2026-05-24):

# Tub Metalwork Repair Plan - 2026-05-18

Purpose: convert the May 17-18 tub rust photo set into a repair sequence for all currently visible metalwork issues before primer, seam sealer, filler, or refit work continues.

Evidence basis:

- Photo import run `20260518T155830` confirmed the selected tub set and added three new files while reusing eleven already-catalogued files.
- Active rust-intake job: `tub_rust_damage_survey_20260517`
- Hinge/corner hold: `tub_corner_hinge_pin_repair_20260517`
- Supporting plan baselines:
  - `docs/j40_welding_execution_plan_20260419.md`
  - `docs/tub-off-refit-execution-plan.md`
  - `docs/fabrication-raw-materials-procurement-estimate-20260513.md`

## What The Photos Show

### 1. Floor-pan corrosion and local perforation

- Multiple floor areas show broad surface rust, pitting, and at least isolated pinholes.
- Rust is concentrated along low points, pressed ribs, bead transitions, and edge returns where moisture has sat under old coatings.
- This is not a full-floor replacement call yet, but it is beyond a simple clean-and-coat job.

### 2. Body-mount and side-seam metal loss

- The tub-side mount/captive-fastener zone shows cracked edges, perforation, and thinning around holes and returns.
- Rust is present in lap/seam interfaces, which means at least part of the loss is trapped between layers rather than only on the exposed face.
- Any spinning, stripped, or weak captive thread in this zone should be treated as a metal rebuild issue, not a hardware-only issue.

### 3. Corner and hinge assembly failure

- The hinge pin had to be cut off.
- The adjacent corner metal is visibly swollen, cracked, and perforated.
- This is the highest-risk zone because it combines rust, alignment, and hardware function in one assembly.

### 4. Aperture and side-shell edge corrosion

- The door/aperture-side shell shows rust at vertical edges, returns, and lower transitions.
- Some of this may stay in the "clean and retain" bucket, but only after the paint, filler, and seam sealer are removed well past the visible staining.

## Repair Standard

- No overlay plates on visible body skin or floor sheet.
- No filler over rust.
- No rust converter trapped inside a seam that is about to be welded closed.
- Any perforated, cracked, or knife-edge-thin metal in a load path or hinge/mount area gets cut out and replaced.
- Every repaired zone must be proven on both faces as far as access allows.

## Material Release

- `1.2 mm` cold-rolled mild steel:
  - floor-pan patch sections
  - small closure patches
  - light skin and lip repairs
- `1.6 mm` cold-rolled mild steel:
  - heavier floor returns
  - edge flanges
  - corner rebuild sections where the original shell is visibly heavier than skin
- `3.0 mm` mild-steel plate:
  - captive-nut backing plates
  - local mount reinforcement coupons
  - hinge-support doubler pieces only where the original part proves to be similar thickness
- Hardware and consumables:
  - replacement captive or weld nuts as required after thread inspection
  - hinge pin stock or replacement hinge hardware if the original bore/pin set is not reusable
  - cutting discs, flap discs, wire cup, weld-through primer for unavoidable closed laps, epoxy primer, seam sealer, and cavity wax

## Work Sequence

### Stage 1. Expose and map everything

1. Strip paint, filler, seam sealer, and loose rust at least `50-75 mm` beyond every visible defect.
2. Tag each zone by exact vehicle station before cutting:
   - floor patch area(s)
   - mount/captive-fastener area(s)
   - hinge/corner assembly
   - aperture edge and lower side-shell returns
3. Probe with pick and hammer, then mark:
   - perforated
   - thin but intact
   - sound after cleanup
4. Photograph every zone after exposure, not just before cleanup.

### Stage 2. Brace and datum the opening

1. Brace the affected opening before the corner or hinge structure is cut apart.
2. Record:
   - hinge spacing
   - pin diameter
   - hinge centerline
   - aperture width/diagonals
3. If the opposite side is intact, use it as the dimensional reference.
4. Keep a temporary alignment rod through hinge knuckles during mock-up and tack-up.

### Stage 3. Rebuild the hinge/corner assembly first

1. Cut out all cracked and perforated hinge-support metal, including any rotten inner box or return hidden behind the outer face.
2. Separate the repair into layers:
   - inner support or box section
   - hinge-support face
   - outer corner or return skin
3. Replace any ovalized, split, or cut-damaged hinge knuckle rather than trying to dress it back into shape.
4. Trial-fit the hinge/pin assembly before final welding.
5. Do not fully finish this zone until the opening shape and hardware movement are proven.

### Stage 4. Rebuild the mount and seam structure

1. Open the seam enough to remove all trapped scale.
2. Re-reference the mount-hole center and captive-nut position before cutting the old plate out.
3. Replace in the same order the factory structure used:
   - backing/reinforcement plate
   - captive-nut or threaded feature
   - outer sheet or return flange
4. Use `3.0 mm` only for the backing/reinforcement layer, not as a substitute for outer shell sheet.
5. Plug-weld back through the flange pattern where the original construction relied on spot-welded layers.

### Stage 5. Repair floor pans and low-point rust

1. After edge structures are stable, decide floor repairs by actual cleaned boundary, not by the rusty stain alone.
2. Any isolated pinhole or thin cluster near a rib, seam, or drain feature should be cut out as a shaped section large enough to reach solid metal.
3. Reproduce beads, steps, and ribs where they add stiffness; do not close them with flat plates if the original pressing can be approximated.
4. Butt-weld flat patches where possible and plug-weld where the floor rejoins an underlying brace or flange.
5. If a floor area remains uniformly solid after cleanup, keep it and coat it rather than replacing sound original steel.

### Stage 6. Clean up aperture-edge and side-shell rust

1. Strip the full vertical edge and lower return until the rust boundary is visible.
2. Localize repairs:
   - edge-lip patch
   - lower return patch
   - small side-skin closure
3. Keep these secondary to the hinge and mount structure, because the edge finish depends on those harder points being correct first.

### Stage 7. Corrosion closure

1. Dress welds only as much as needed for fit and sealing.
2. Blow out dust, degrease, and apply epoxy primer to all bare steel.
3. Seam-seal only after the metal is fully verified and dry.
4. Apply the selected top protection by zone.
5. Flood closed sections and rebuilt seams with cavity wax after primer/topcoat cure.

## Pass/Fail Gates

- No visible perforation remains at any cut edge.
- No cracking remains around hinge supports, mount holes, or seam returns.
- Hinge pin passes through the rebuilt hinge stack without bind.
- Captive threads accept the correct fastener cleanly and hold torque without spinning.
- Floor repairs have no pinholes under backlight or air test.
- Primer covers all repaired bare metal before the shell sits outside or collects workshop moisture again.

## Practical Priorities

### P0: Must be rebuilt, not merely cleaned

- Hinge/corner assembly with the cut hinge pin
- Perforated or cracked body-mount/captive-fastener metal
- Any seam section that opens up or delaminates when cleaned

### P1: Repair after cleanup confirms the final cut lines

- Floor-pan pinholes and thin low-point sections
- Rusted edge returns adjacent to repaired mount or corner zones

### P2: Clean, verify, and retain if sound

- Broad floor surface rust away from perforations
- Aperture-edge staining that cleans back to full thickness

## Unknowns Still To Close

- Exact hidden condition behind the corner/hinge outer face
- Whether the captive-nut structures are reusable or need full replacement
- Whether the floor corrosion is still localized after full stripping, or expands into larger continuous thin sections
- Whether previous body filler or old repairs are hiding wider cut lines

## Recommended Next Action

Run one controlled metal-exposure pass on the hinge/corner zone and one mount/seam zone first. Those two openings will tell you whether the current job remains a localized patch program or needs a larger sectional rebuild package.

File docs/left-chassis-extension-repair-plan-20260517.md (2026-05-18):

# Left Chassis Extension Repair Plan - 2026-05-17

Evidence:

- User attachments on 2026-05-17 showing the left chassis extension with a rough lower-side cut-out.

## Decision

Treat this as a `P0` chassis repair hold before final primer, seam sealer, Raptor, or cavity wax.

The visible cut-out looks like a non-factory clearance notch, possibly made for an old exhaust route. The repair target is to restore the chassis extension to its original closed lower-side profile, then route the exhaust around the restored rail rather than cutting the frame again.

Do not cover this with filler, seam sealer, Raptor, or an external cosmetic plate. Repair metal first, validate geometry, then coat.

## Photo Read

- The left rail/extension has a rough semicircular section missing from the lower side wall.
- The cut edge is jagged and oxidized, which suggests previous modification rather than a clean factory relief.
- Adjacent bracketry, body-mount/crossmember structure, and rail fasteners are still present, so the missing section should be repaired in context rather than replaced by a generic flat patch.
- Nearby exhaust or hanger planning must be reopened because the old clearance path should not remain the design driver.

## Repair Principle

Restore the rail profile from measured evidence, not from guesswork.

Primary geometry source:

1. Mirror the intact opposite-side chassis extension profile if it is sound and unmodified.
2. Use fixed datums visible on both sides: rivets/bolts, bracket edges, body-mount pedestal, rail top edge, flange crease, and nearby crossmember/bracket junctions.
3. Confirm with any factory chassis drawing or known good reference only if available.

If the opposite side has different bracket details, copy the base rail/extension wall and lower flange shape only, not unrelated bracket features.

## Measurement And Inspection Gate

Before cutting or welding:

1. Degrease and wire-brush at least `75 mm` around the cut-out on both sides of the rail wall.
2. Photograph the repaired zone-to-be square-on, from below, and from inside/behind if accessible.
3. Probe the cut edge and adjacent lower flange for thin metal, laminating rust, cracks, and old weld repairs.
4. Measure actual chassis metal thickness with calipers where the edge is clean.
5. Make a cardboard profile template from the intact opposite side.
6. Transfer the template to the damaged side and mark the original rail outline in paint marker.
7. Check rail straightness and symmetry with a straightedge and diagonal measurements before welding.
8. Confirm nearby body mount, bracket, and hard-line/fuel/brake routing are not disturbed.

Stop and expand the repair if the metal around the notch is thin, cracked, delaminated, or previously patched poorly.

## Fabrication Method

Preferred repair:

1. Trim only enough jagged metal to reach clean, sound steel with smooth radiused corners.
2. Form a matching mild-steel insert from the measured chassis thickness, including the lower side-wall curve/return profile if present.
3. Use a butt-welded patch where the rail wall is simple and access is good.
4. Use an internal backing sleeve or shaped internal doubler only if needed for alignment or strength. If used, plug-weld it and protect the closed cavity afterward.
5. Avoid square-ended external fishplates unless a chassis fabricator specifically releases reinforcement. If reinforcement is needed, use tapered/radiused ends so stress is not concentrated.
6. Tack the insert with the rail fixed in its natural position, then stitch-weld in short alternating runs to control heat and distortion.
7. Grind only enough to remove sharp/high weld profile. Do not thin the surrounding chassis wall chasing a cosmetic finish.
8. Reopen or preserve any drain, bolt, clip, or bracket clearance that existed in the original shape.

The welder should be a competent chassis/structural automotive welder. This area should not be treated as thin body-panel work.

## Exhaust Reroute Gate

The exhaust must be mocked up after the rail shape is restored.

Requirements:

1. No exhaust pipe should pass through, touch, or require a new notch in the chassis rail/extension.
2. Target at least `25-30 mm` clearance to painted chassis/body surfaces wherever possible.
3. Use larger clearance and/or heat shielding near brake lines, fuel lines, rubber mounts, wiring, bushings, and paint-sensitive surfaces.
4. Check clearance at engine movement, suspension droop/compression, steering movement, axle movement, and body/tub refit position.
5. Add or repair exhaust hanger tabs before final coating if any welded tabs are required.
6. Use proper rubber exhaust hangers so pipe movement is controlled and cannot beat against the repaired rail.

If the new exhaust route needs a hanger, bracket, or heat shield mount on the chassis, include it in the existing pre-coating bracket release workflow.

## Coating And Corrosion Protection

After welding and inspection:

1. Remove weld scale and spatter.
2. Inspect welds for undercut, porosity, pinholes, missed edges, or distortion.
3. Use dye penetrant or another crack check if available, especially at the old notch ends.
4. Epoxy-prime bare steel inside and outside before seam sealing.
5. Seam-seal only after primer where the coating system requires it.
6. Apply Raptor/top protection only after the repair is signed off.
7. Cavity-wax the inside/overlap/backing area last, after primer/top protection has cured.
8. Keep drains, bolt holes, threads, and ground points open and serviceable.

## Acceptance Criteria

The repair is released only when:

- The lower rail/extension profile matches the known-good side or verified reference.
- There are no jagged cut edges, unsealed lap traps, open pinholes, undercut welds, or visible cracks.
- Rail straightness and local bracket/body-mount alignment are unchanged.
- The nearby body mount, crossmember/bracket, lines, and clips still fit and remain serviceable.
- The exhaust mock-up clears the restored rail without contact through expected movement.
- Welded hanger or heat-shield tabs, if required, are finished before final coating.
- Bare metal is epoxy-primed, protected, and cavity-waxed in the correct order.

## Workshop Instruction Summary

Plain instruction for the fabricator:

"Restore the missing section in the left chassis extension back to the original rail profile. Use the opposite side as the template, measure the steel thickness, form a matching insert, weld it as a structural chassis repair, and do not leave an exhaust clearance notch. After the repair, mock up the exhaust around the restored rail with proper hanger support and heat clearance before primer/Raptor."

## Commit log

2026-04-30 Initial project metadata, scripts, and generated indexes
    [bodywork.csv, build_plan.csv, comms_ingest_2026-04-27_categorized.csv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]
2026-04-30 Add archive media batch 01
    [bilal_ganj_market_list.csv, p2_market_list.csv, p2_market_list_with_eps.csv]
2026-04-30 Add archive media batch 02
    [bilal_ganj_detailed_size_list_v3.csv, bilal_ganj_quick_list.csv, j40_master_buy_list_line_by_line_20260415.csv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]
2026-04-30 Add archive media batch 03
    [bilal_ganj_detailed_size_list_v3.csv, bilal_ganj_quick_list.csv, j40_master_buy_list_line_by_line_20260415.csv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]
2026-04-30 Add archive media batch 04
    [bilal_ganj_detailed_size_list_v3.csv, bilal_ganj_quick_list.csv, j40_master_buy_list_line_by_line_20260415.csv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]
2026-04-30 Add archive media batch 05
    [bilal_ganj_detailed_size_list.csv, bilal_ganj_detailed_size_list_v3.csv, bilal_ganj_market_list.csv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]
2026-04-30 Add archive media batch 06
    [bilal_ganj_detailed_size_list_v3.csv, bilal_ganj_quick_list.csv, j40_simple_buy_list_20260415.csv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]
2026-04-30 Add archive media batch 07
    [bilal_ganj_detailed_size_list_v3.csv, bilal_ganj_quick_list.csv, j40_master_buy_list_line_by_line_20260415.csv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]
2026-04-30 Add archive media batch 08
    [bilal_ganj_detailed_size_list_v3.csv, bilal_ganj_quick_list.csv, fastener_cart_best_guess_20260417.csv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]
2026-04-30 Add archive media batch 15
    [cluster_assignments.csv]
2026-04-30 Sync latest planning and workbook updates
    [build_plan.csv, expenses.csv, hardware_budget_dedup.csv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]
2026-04-30 Refresh workbook planning outputs
    [hardware_budget_dedup.csv, j40-master-tracker.xlsx, j40_costs_cost_tabs_tidy.csv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]
2026-04-30 Update J40 inventory and procurement dashboard
    [build_plan.csv, component_disposition_plan.csv, electrical_master.csv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]
2026-05-02 Update project dashboard data and media
    [body_mount_order_release_specs.csv, body_mount_release_actions.csv, body_mount_station_closure_sheet.csv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]
2026-05-02 Add replacement pipe release tracking
    [expenses.csv, parts_buy_now_this_week.csv, procurement_queue.csv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]
2026-05-02 Fix dashboard image loading
    [expenses.csv, workstream_status.csv]
2026-05-02 Update project dashboard and reference data
    [component_disposition_plan.csv, expenses.csv, inventory_image_overrides.csv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]
2026-05-02 Update project planning data and reference catalog
    [build_plan.csv, component_disposition_plan.csv, component_jobs.csv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]
2026-05-02 Add Toolsmart order images and procurement rows
    [expenses.csv, inventory_image_overrides.csv, manifest.csv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]
2026-05-02 Fix heat glow plugs duplicate
    [j40_costs_expenses_reconciliation.csv]
2026-05-02 Mark received tool orders from email evidence
    [expenses.csv, j40_costs_cost_tabs_tidy.csv, j40_costs_expenses_reconciliation.csv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]
2026-05-02 Mark received welding tools
    [expenses.csv, orders_receipts_audit_queue.csv, procurement_queue.csv]
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2026-05-02 Add replacement pipe photo intake
    [component_jobs_photo_reconciliation.csv, import_history_personal.csv, manifest.csv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]
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2026-05-02 Add explicit pipe lengths to replacement specs
    [expenses.csv, procurement_queue.csv, replacement_pipe_ordering_specs.csv]
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2026-05-03 Update brake suspension planning and pipe dashboard
    Add merged suspension/brake work plan and order-link notes.
    Simplify replacement-pipe board in the project control UI and refresh generated tracker data.
    Move hardware refinish photos into the correct stage index.
    [brake_system_requirements.csv, component_jobs.csv, expenses.csv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]
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2026-05-12 Update J40 dashboard planning and photo intake
    Import May 12 Google Photos into the project catalog and dashboard evidence.
    Update EPS, fabrication, brakes, procurement, and received-order workstreams with current planning data.
    Refresh generated dashboard data and related catalog/reconciliation outputs.
    [brake_system_requirements.csv, chassis_bracket_analysis_register_20260508.csv, component_jobs.csv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]
2026-05-12 Import radiator measurements and improve workstream tables
    Add the May 12 radiator fixing measurement photos and steering-column reference import.
    Update chassis bracket tasks, photo inventory, reconciliation, and dashboard data from the new evidence.
    Move workstream table images into row-level evidence strips and widen text columns.
    [chassis_bracket_analysis_register_20260508.csv, component_jobs.csv, component_jobs_photo_reconciliation.csv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]
2026-05-12 Improve chassis fixing dashboard layout
2026-05-12 Show all chassis fixing evidence images
    [chassis_bracket_analysis_register_20260508.csv]
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2026-05-15 Correct battery carrier cutoff routing
    [cavity_mapping_plan.csv, component_jobs.csv, component_layout.csv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]
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2026-05-15 Add Relay Rev D and adjustable battery carrier offset
    [battery_stand_adjustable_offset_bar_rev_b.dxf, cavity_mapping_plan.csv, component_jobs.csv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]
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2026-05-18 Tighten ordering view filter
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2026-05-27 Move brake work gates out of ordering ledgers
    [brake_hard_line_tool_parts_selection.csv, brake_system_requirements.csv, expenses.csv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]
2026-05-27 Treat rear drum brake holds as split gates
    [brake_system_requirements.csv, expenses.csv, orders_receipts_audit_queue.csv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]
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2026-05-27 Add missing J40 rubber weatherstrip controls
    [longman_rubber_order_specs.csv, rubber_hose_component_audit.csv, rubber_ordering_specs.csv]
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2026-05-29 Update Amir pipe list and CAD photo assets
    [brake_system_requirements.csv, component_jobs_photo_reconciliation.csv, import_history_personal.csv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]
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2026-05-29 Record front disc brake replacement decision
    [brake_system_requirements.csv, expenses.csv, orders_receipts_audit_queue.csv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]
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2026-05-29 Improve J40 vehicle map from reference gallery cues
    [j40_full_vehicle_scaffold_rev_b.scad, j40_full_vehicle_scaffold_rev_b_orthographic.dxf, j40_full_vehicle_scaffold_rev_b_parts.csv]
2026-05-29 Update project control data from May 29 photo intake
    [b_60010_long_measurement_model.scad, b_60010_rear_pair_measurement_model.scad, b_60020_short_measurement_model.scad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]
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2026-05-29 Update Amir procurement tasks and front disc split
    [brake_system_requirements.csv, expenses.csv, front_disc_component_order_options.csv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]
2026-05-29 Use on-hand clips and brake tees by location
    [brake_hard_line_tool_parts_selection.csv, brake_system_requirements.csv, comms_ingest_2026-05-30_categorized.csv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]
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2026-05-30 Fix J40 CAD evidence pipeline inputs
    [j40_digital_twin_evidence_matrix.csv, j40_digital_twin_measurement_backlog.csv]
2026-05-30 Add J40 as-fitted route and LHD review model
    [j40_as_fitted_route_model_coverage_20260531.csv, j40_as_fitted_route_model_scope_20260531.csv, j40_digital_twin_evidence_matrix.csv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]
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2026-07-19 Add passenger footwell floor replacement scope
    [component_jobs.csv]
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2026-07-31 Add CNC dashboard LCD and HVAC fascia package
    [dashboard_main_fascia_rev_a.dxf, dashboard_rear_stiffening_frame_rev_a.dxf, fabricator_cut_list.csv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]
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2026-07-31 Correct dashboard LCD scale and seven-selector layout
    [centre_fascia_template_rev_c.dxf, centre_three_selector_strip_blank_rev_c.dxf, fabricator_cut_list.csv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]
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2026-08-01 Fix radiator frame mounts and aligned electrical layout
    [rev_g_toyota_donor_purchase_list.csv]
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2026-08-01 fix: attach radiator render to original top holes
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2026-08-02 Audit dashboard rear clearance and LCD depth
    [cnc_measurement_schedule.csv, manifest.csv, rear_clearance_photo_evidence_20260802.csv]
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2026-08-16 Update J40 portal, fabrication plans, handbrake specs, and photo archive
    [comms_ingest_2026-08-15_categorized.csv, component_jobs.csv, component_jobs_photo_reconciliation.csv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]
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2026-08-16 Simplify replacement pipes board
    [replacement_pipe_board_evidence.csv]
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2026-08-16 Use selected replacement pipe comparisons
    [replacement_pipe_board_evidence.csv]
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
